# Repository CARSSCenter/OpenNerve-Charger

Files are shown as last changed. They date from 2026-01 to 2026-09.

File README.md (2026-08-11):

## About
This repository holds the PCBA files, firmware, and design files for the OpenNerve charger.
The charger is designed to be compatible with the [OpenNerve Implantable Pulse Generator](https://github.com/CARSSCenter/OpenNerve-Implantable-Pulse-Generator) and to inductively charge it at 300kHz.

charger

## Instructions for Use
BTNs behavior 
Regarding the button functionalities:

    BTN1 changes the state from WAIT to SCAN. If pressed during CHARGE state, it interrupts charging and returns to WAIT.
    BTN2 performs an immediate MCU reset from any state. Use this to recover from a firmware hang without disconnecting power.
    BTN3 enables DFU mode and resets the device to boot in DFU mode.

DFU mode allows firmware updates over USB-C.

LED behavior
The left LED shows the current state:

    OFF → WAIT
    Blue → SCAN
    White → SLOW_CHARGE_AND_SCAN 
    Yellow → CHARGE (connected and charging)

The middle LED turns Green when charging is complete.

Below is a more detailed summary of the firmware state machine, main transitions, and LEDs colors:

States: INITIALIZATION, WAIT, SCAN, SLOW_CHARGE_AND_SCAN, CHARGE

Note: BTN2 (MCU reset) is available in all states and bypasses the state machine entirely. Pressing BTN2 disables WPT and the VCC regulator, then immediately resets the MCU. The device boots back to WAIT.

STATE: INITIALIZATION (initializes BLE, WPT, and PMC subsystems)

    BLE_INITIALIZED → WAIT
    BTN2 PRESSED → MCU RESET
    BUTTON_DFU_PRESSED (BTN3) → DFU mode

STATE: WAIT

    BTN1 PRESSED → SCAN
    BTN2 PRESSED → MCU RESET
    BTN3 PRESSED → DFU mode

STATE: SCAN (Blue Left LED ON)

    BLE_DEVICE_FOUND → CHARGE
    BLE_SCAN_TIMEOUT → SLOW_CHARGE_AND_SCAN
    BTN2 PRESSED → MCU RESET
    BTN3 PRESSED → DFU mode

STATE: SLOW_CHARGE_AND_SCAN (White Left LED ON)

    BLE_DEVICE_FOUND → CHARGE
    BLE_SCAN_TIMEOUT → WAIT
    WPT_SCAN_TIMEOUT → WAIT
    BTN2 PRESSED → MCU RESET
    BTN3 PRESSED → DFU mode

STATE: CHARGE (Yellow Left LED ON / middle LED Green when complete)

    CHARGE_COMPLETE → WAIT (middle LED Green ON)
    BTN1 PRESSED → WAIT (stop charge)
    WPT_SCAN_TIMEOUT → WAIT
    TEMPERATURE_CRITICAL (IPG ≥ 41°C) → WAIT (thermal protection)
    BTN2 PRESSED → MCU RESET
    BUTTON_DFU_PRESSED (BTN3) → DFU mode

In summary, after the charger is connected and initialization finishes, the device enters the WAIT state. If BTN1 is pressed, the device enters SCAN mode and the left LED turns blue. If a device is found, the charger transitions to CHARGE and the left LED turns yellow. If no device is found, the charger enters SLOW_CHARGE_AND_SCAN and the left LED turns white. If the device is still not found after that period, the system returns to WAIT (all LEDs off).
If a device is found during the slow scan, the system transitions to CHARGE. Once charging is completed, the middle LED turns green and the system returns to WAIT. During charging, if BTN1 is pressed, the device returns to the WAIT state. Charging also stops automatically if the IPG temperature rise above 41°C (thermal protection) or if the WPT status times out.
If the firmware becomes unresponsive at any point, BTN2 can be used to reset the MCU and return to WAIT without disconnecting power.

## Instructions for Firmware Development and Flashing
Instructions on how to set up the development environment and compile firmware can be found in the firmware folder's [readme](Firmware/README.md).
### To flash:
1. Install J-Link software: https://www.segger.com/downloads/jlink (when installing, check the box to install legacy USB Driver)
2. Attach J-Link EDU Mini USB cable to Windows computer and in Device Manager confirm that J-Link driver is under USB devices (If it is not there, start J-Link Configurator, right-click on J‐Link EDU Mini, Update FW > Configure > select WinUSB driver > OK)
3. Attach Tag-Connect cable to the charger PCB, open the J-Flash Lite, confirm that Target device is NRF52, and click OK.
4. Click Erase Chip to remove previous FW.
5. Download the two hex files from the Firmware folder.
6. Flash the SoftDevice:
    * Click the “…” button and select 140_nrf52_7.2.0_softdevice.hex 
    * Click Program Device
7. Flash the application:
    * Click the “…” button and select wpt-charger.hex 
    * Click Program Device
      
## Contributors
* [Focus Uy](https://focus.uy/) 
* [Medipace Inc](https://www.medipaceinc.com/) 

## Disclaimer
The contents of this repository are subject to revision. No representation or warranty, express or implied, is provided in relation to the accuracy, correctness, completeness, or reliability of the information, opinions, or conclusions expressed in this repository.

The contents of this repository (the “Materials”) are experimental in nature and should be used with prudence and appropriate caution. Any use is voluntary and at your own risk.

The Materials are made available “as is” by USC (the University of Southern California and its trustees, directors, officers, employees, faculty, students, agents, affiliated organizations and their insurance carriers, if any), its collaborators Med-Ally LLC and Medipace Inc., and any other contributors to this repository (collectively, “Providers”). Providers expressly disclaim all warranties, express or implied, arising in connection with the Materials, or arising out of a course of performance, dealing, or trade usage, including, without limitation, any warranties of title, noninfringement, merchantability, or fitness for a particular purpose.

Any user of the Materials agrees to forever indemnify, defend, and hold harmless Providers from and against, and to waive any and all claims against Providers for any and all claims, suits, demands, liability, loss or damage whatsoever, including attorneys' fees, whether direct or consequential, on account of any loss, injury, death or damage to any person or (including without limitation all agents and employees of Providers and all property owned by, leased to or used by either Providers) or on account of any loss or damages to business or reputations or privacy of any persons, arising in whole or in part in any way from use of the Materials or in any way connected therewith or in any way related thereto.

The Materials, any related materials, and all intellectual property therein, are owned by Providers.

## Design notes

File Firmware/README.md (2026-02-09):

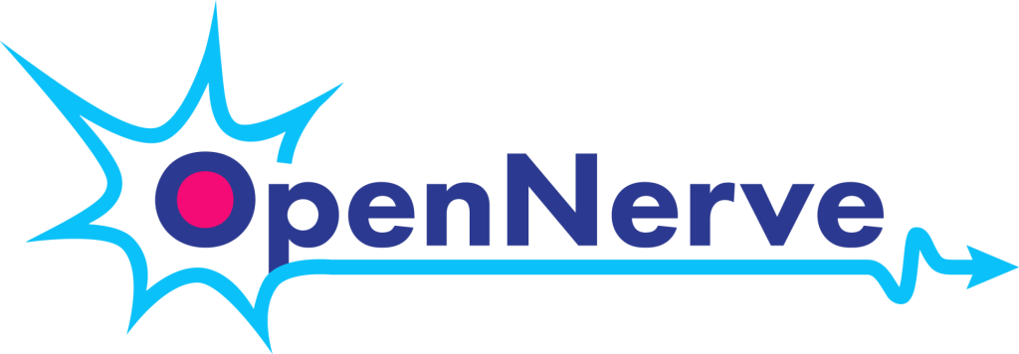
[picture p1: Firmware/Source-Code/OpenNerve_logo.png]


# WPT Charger Embedded Software Development

## Generalities
This repository is dedicated to the development of the WPT Charger embedded software. 

## Getting Started
This section outlines the essential steps to establish a functional environment for building and flashing the application to the WPT Charger. If you are planning to engage in development, refer to the Development section for additional steps that must be followed.

### Install SEGGER IDE
The SEGGER IDE v8.10c is currently being used to compile and flash the application. You can download it [here](https://www.segger.com/downloads/embedded-studio). 

## Development
If you are involved in the development of this project, in addition to the Getting Started section, follow the next steps to set up your development environment.

### Install Python
Install [Python 3.11.3](https://www.python.org/downloads/).

ⓘ Note: If you are running Linux or macOS, consider using `pyenv` to install multiple, independent Python versions.

### Install Git
Install [Git](https://git-scm.com/downloads).

### Set build tool paths
Set build tool paths to use the build tool. Inside the `build_tool` path you will find the `config.ini.example` file. You should copy this, rename it to `config.ini`, and edit it to set your own paths. In addition, you should update the environment variables by adding the `bin` directory of SEGGER to the system's `PATH`. 
After this, you can run the build tool in a Windows PowerShell in build tool path using one of these commands depending on whether you want to build for the devkit or the PCBA:
```
py .\run_build_tool.py --board devkit
```
```
py .\run_build_tool.py --board pcba
```

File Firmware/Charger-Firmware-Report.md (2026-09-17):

# WPT Charger — Firmware Implementation Report

**Hardware:** Hornet WPT Charger PCBA
**MCU:** nRF52840 (via nRF5 SDK)
**Repo path:** `Firmware/Source-Code/`

---

## 1. Overview

The charger firmware manages the complete wireless power transfer (WPT) charging session from user button press to battery full. It communicates with the IPG entirely through BLE advertisement scanning — the IPG broadcasts its charging status, thermistor readings, and GPIO state in a Manufacturer-Specific Data (MSD) payload every second while charging, and the charger uses that data to make power and thermal decisions.

The firmware is built on an **event-driven architecture (EDA)** framework. The application layer, BLE service, WPT service, and PMC service each run their own state machines and communicate exclusively by sending events to each other's ports. No state machine inspects another's internal state directly.

---

## 2. Hardware Overview

### 2.1 WPT Controller — LTC4125

The LTC4125 is the wireless power transmitter IC. In normal operation, LTC4125 autonomously runs an "Optimum Power Search (OPS)" algorithm to find the power level at which the receiver (IPG) is best coupled, using the reflected impedance from the secondary coil to determine best coupling. However, this firmware operates differently; by actively driving the `PTH1`/`PTH2` pins via a 16-bit SPI DAC (DAC80504), the pulse width / power transfer is directly controlled (higher DAC voltage → larger allowed duty cycle → more power delivered).

There are 13 DAC steps (0–12), each corresponding to an increasing power transmission level. It is important to understand what the step actually sets: PTH is a **ceiling** on the LTC4125's internal pulse-width search, not a forced output level. Lowering the step changes delivered power only once the ceiling constrains the search below what the load is drawing. Consequently the control algorithm searches for the lowest ceiling the IPG still accepts — see **6.3 Adaptive Power Control** — and PGOOD typically stays high through several descending steps before anything changes.

| DAC voltage | Step | Role |
|---|---|---|
| 400 mV | 0 (minimum) | Floor of the search range |
| 500 mV | 1 | Cold-start level (`COLD_START_LEVEL`) — the reset level and the first step of the cold-start ramp |
| … | … | Cold-start ramp steps, one every 30 s |
| 1600 mV | 12 (maximum) | Maximum — top of the cold-start ramp |

**CTD pin:** LTC4125 `CTD` (pin 14) has a 36 pF capacitor to GND, which sets the delay between OPS cycles. MCU pin **P0.05 (`WPT_CTD_CTRL`)** drives a MOSFET gate; when that MOSFET is on, it shorts the capacitor and ties `CTD` directly to GND.

`WptManager::ConfigureGpios()` configures P0.05 as an output and writes it **HIGH** during initialization, then never changes it — so for the entire session the MOSFET is on and `CTD` is held at GND, bypassing the 36 pF timing capacitor.

> ⚠️ **Unresolved — needs a datasheet check and a scope on pin 14.** Three things point the same direction and have not been reconciled:
> - The GPIO configuration sits under a comment claiming it is "commented out because the CTD pin is not implemented in the prototype." It is not commented out; it is live code.
> - `Wpt_LTC4125::StopSearch()` and `ResumeSearch()` (`hal_wpt.cpp:59-69`) are empty stubs whose own comments state *"Write 1 to the CTD pin to stop the search"* and *"Write 0 to the CTD pin to resume."* By that convention, initialization writes the **stop-search** value, and the functions intended to control it do nothing. `StopWptScan()` therefore has no effect.
> - An earlier revision of this report asserted that grounding CTD stops the search after the first OPS cycle.
>
> Against that, power delivery demonstrably works and PGOOD does go high in testing. Either the polarity interpretation is wrong, or a single OPS cycle is sufficient given that the DAC drives PTH directly and overrides the search anyway. Worth settling before relying on `StopSearch()`/`ResumeSearch()` for anything.

### 2.2 DAC — DAC80504

16-bit quad-channel SPI DAC. Only CHANNEL_1 is used to drive `PTH1`/`PTH2`. `Dac80504::Init()` configures it with `ReferenceDivider::DIVIDER_OFF` and **`Gain::DOUBLE_GAIN`** (`hal_dac.cpp:35`), so with `REFERENCE_VOLTAGE = 2500 mV` the full-scale output is **5000 mV**, not 2500 mV. The `LDAC` pin is toggled after each SPI write to latch the new value.

```
DAC voltage = 400 mV + (step × 100 mV)    step ∈ [0, 12]
```

> **Note:** `hal_dac.h:65` defines `MAX_OUTPUT_VOLTAGE = 2500`, which is inconsistent with the configured 2× gain. That constant is unused anywhere in the codebase — do not treat it as the full-scale value.

### 2.3 Key GPIO / Analog Pins

Values below are for `BOARD == PCBA`. `hal_pinout.h:65-111` defines a materially different `DEV_KIT` pinout (e.g. `WPT_EN` on P0.28, `WPT_NTC` on P0.29 as a plain GPIO rather than AIN6) — check the build's `BOARD` setting before using these for bring-up.

| Signal | Pin | Direction | Notes |
|---|-----|---|---|
| `WPT_EN` | P1.15 | Output | LOW = LTC4125 enabled (active-low) |
| `WPT_STAT` | P0.7 | Input | LTC4125 load-detection status (see §11 — `GetStat()` is a stub) |
| `WPT_CTD_CTRL` | P0.5 | Output | HIGH = MOSFET on = LTC4125 `CTD` shorted to GND (see §2.1) |
| `WPT_NTC` | AIN6 | Analog | Local NTC thermistor on charger PCB (see §11 — conversion is broken) |
| `WPT_IMON` | AIN5 | Analog | Coil current monitor |
| `DAC_CS` | P0.11 | Output | DAC chip select (SPI) |
| `DAC_LDAC` | P0.12 | Output | DAC latch |
| `PMC_VCC_EN` | P0.20 | Output | Enables power management circuit |
| `SCLK` | P1.9 | Output | SPI clock |
| `MOSI` | P1.8 | Output | SPI MOSI |
| `MISO` | P0.8 | Input | SPI MISO |

### 2.4 LED Indicators

| LED state | Meaning |
|---|---|
| Blue (scanning) | Scanning for IPG — BLE scan active |
| White (slow charge) | Coil powering up a switched-off IPG — waiting for BLE |
| Yellow (charging) | IPG found, WPT active, batteries charging |
| Green (charged) | All batteries full |
| Magenta (manual) | **Debug builds only** — `StateManual`, operator driving the coil over RTT (§4.7) |

---

## 3. Firmware Architecture

### 3.1 Layer Structure

```
┌─────────────────────────────────────────────┐
│              Application Layer              │
│  app_state_machine.cpp / app_system.cpp     │
│  state_wait / state_scan / state_charge /   │
│  state_slow_charge_and_scan /               │
│  state_initialization /                     │
│  state_manual (debug builds only)           │
├─────────────────────────────────────────────┤
│              Service Layer                  │
│  BLE: svc_ble_manager / svc_ble_subsystem   │
│  WPT: svc_wpt_manager / svc_wpt_subsystem   │
│  PMC: svc_pmc_subsystem                     │
│  Debug: svc_debug_console (debug builds)    │
├─────────────────────────────────────────────┤
│               Core Layer                    │
│  EDA framework: state machines, active      │
│  objects, ports, timers, queues             │
├─────────────────────────────────────────────┤
│               HAL Layer                     │
│  hal_ble / hal_wpt / hal_dac / hal_led /    │
│  hal_dfu / hal_adc                          │
└─────────────────────────────────────────────┘
```

### 3.2 Port / Event Model

Each subsystem exposes a **port** (a message queue). State machines communicate by calling `Port::SendEvent(event, optData)` rather than calling each other directly. This decouples layers — the application layer sends `WptPort::WPT_POWER_ON` and the WPT service handles it in its own context.

**System events** (`app_port.h`):

| Event | Meaning |
|---|---|
| `BLE_INITIALIZED` | BLE stack ready |
| `BLE_DEVICE_FOUND` | IPG advertisement received |
| `BLE_SCAN_TIMEOUT` | No advertisement within scan window |
| `WPT_SCAN_TIMEOUT` | WPT-level scan timed out |
| `BATTERY_CHARGED` | All batteries full |
| `BUTTON_PRESSED` | User pressed the power button |
| `BUTTON_DFU_PRESSED` | DFU mode button combo |
| `TURN_OFF` | Formerly the thermal shutdown path; thermal faults no longer reach the application layer at all (§6.5). In a **production** build nothing sends it and the handler at `state_charge.cpp:60` is unreachable. In a **debug** build the RTT console's `n` command sends it to leave `StateManual` (`state_manual.cpp:67`). |
| `MANUAL_TAKEOVER` | **Debug builds only** (0x12). Sent by the RTT console's `m` command; each operational state transitions to `StateManual` on it (§4.7). Safe despite `MAX_EVENT_ENUM_LENGTH = 20`: `SystemPort::ExecuteEvent` dispatches straight to the state machine and never indexes `mEventCallback`. |

**WPT service events** (`svc_wpt_port.h`):

| Event | Value | Meaning |
|---|---|---|
| `WPT_POWER_ON` | 0x03 | Enable LTC4125, begin OPS |
| `WPT_POWER_OFF` | 0x07 | Disable LTC4125 |
| `WPT_FAULT_CONDITION` | 0x08 | Fault detected |
| `WPT_BATTERY_CHARGING` | 0x09 | BLE confirms charging in progress |
| `WPT_BATTERY_CHARGED` | 0x0B | BLE confirms all batteries full |
| `WPT_SLOW_CHARGE` | 0x0C | Begin the open-loop cold-start ramp (step 1, +1 step every 30 s until an advertisement or step 12) |
| `WPT_SCAN_TIMEOUT` | 0x0D | Power search timed out |
| `WPT_ADJUST_POWER` | 0x0E | Set specific DAC step. Handled in `StateCharging` and `StateSlowCharge`; **dropped** in `StateIdle` (§6.1) |
| `WPT_FAULT_PAUSE` | 0x0F | Suspend coil output; `optDataAddress` carries the `PauseReason_e` (`PAUSE_THERMAL`, `PAUSE_OVP`, or in debug builds `PAUSE_MANUAL`) |
| `WPT_FAULT_RESUME` | 0x10 | Clear one pause reason; `optDataAddress` carries the `PauseReason_e` |
| `WPT_MANUAL_IDLE` | 0x11 | **Debug builds only.** Sent by `StateManual::Entry()`; every WPT state stops the coil and settles in `StateIdle` with fault monitoring only (§4.7) |

`WPT_FAULT_PAUSE`/`WPT_FAULT_RESUME` replaced the earlier `WPT_THERMAL_PAUSE`/`WPT_THERMAL_RESUME` pair at the same event values, generalized to carry a reason so thermal and OVP can share one pause mechanism (see §6.2). The debug console reuses the same pair with `PAUSE_MANUAL` for its coil stop/start. Manual mode adds exactly one WPT event, `WPT_MANUAL_IDLE` (0x11, debug builds only) — kept to one because callbacks registered on a port are stored in a 20-entry array indexed by event ID (`eda_port.h:13`).

---

## 4. Application State Machine

### 4.1 States and Transitions

```
                     power on
                         │
                         ▼
                ┌─────────────────┐
                │  StateInit      │ ← BLE + WPT + PMC subsystems initialized
                └────────┬────────┘
                         │ BLE_INITIALIZED
                         ▼
         ┌──────────────────────────────┐
         │           StateWait          │ ← LEDs off, idle
         └──────────────┬───────────────┘
                        │ BUTTON_PRESSED
                        ▼
         ┌──────────────────────────────┐
         │          StateScan           │ ← Blue LED, BLE scanning (10 s)
         └────┬─────────────────────────┘
              │                         │
    BLE_DEVICE_FOUND            BLE_SCAN_TIMEOUT
              │                         │
              ▼                         ▼
   ┌──────────────────┐    ┌────────────────────────────┐
   │   StateCharge    │    │   StateSlowChargeAndScan   │ ← White LED
   │  (Yellow LED)    │    │   Cold start: step 1, +1   │
   └──────┬───────────┘    │   every 30 s up to 12      │
          │                │   BLE scanning (390 s)     │
          │                └──────────┬─────────────────┘
          │                          │ BLE_DEVICE_FOUND
          │                          │
          │    ◄─────────────────────┘
          │
          │ BATTERY_CHARGED → StateWait (green LED)
          │ BUTTON_PRESSED  → StateWait
          │ TURN_OFF        → StateWait   (unreachable in production builds — see §3.2)
          │ WPT_SCAN_TIMEOUT → StateWait  (thermal blind-retry give-up only — see §6.5, §11)
```

**Debug builds add `StateManual` (§4.7).** `StateWait`, `StateScan`, `StateSlowChargeAndScan` and `StateCharge` each move to it on `MANUAL_TAKEOVER`; only `TURN_OFF` (the console's `n`) returns it to `StateWait` — Button 1 is ignored there. It is not drawn above because it does not exist in a production build.

### 4.2 StateInitialization

Entry sends `INITIALIZE` to the BLE, WPT, and PMC subsystem ports. When `BLE_INITIALIZED` is received, transitions to `StateWait`. This is the only state where subsystem initialization occurs.

### 4.3 StateWait

Idle state. No LEDs, no scanning, no WPT. Transitions to `StateScan` on `BUTTON_PRESSED`, and in debug builds to `StateManual` on `MANUAL_TAKEOVER`. "No WPT" does not imply VCC_EN is low: arriving from `StateCharge` leaves the rail up, because `StateCharge::Exit()` never sends `PMC_POWER_OFF` (§4.6).

### 4.4 StateScan

```
Entry:
  BlePort::START_SCANNING
  hal::Leds::LedScanOn(true)       ← blue LED

DispatchEvent:
  BLE_DEVICE_FOUND:
    mWptManager.StartIpgTemperaturePgoodMonitoringTimer()
    → ChangeState(StateCharge)

  BLE_SCAN_TIMEOUT:
    mWptManager.StopIpgTemperaturePgoodMonitoringTimer()
    → ChangeState(StateSlowChargeAndScan)

  BUTTON_DFU_PRESSED:
    hal::Dfu::start_dfu_mode()

  MANUAL_TAKEOVER:                    (debug builds only)
    → ChangeState(StateManual)

Exit:
  WptPort::WPT_POWER_ON            ← transitions WPT SM StateIdle → StateCharging
  hal::Leds::LedScanOn(false)
```

When no IPG is found within the 10-second scan window, the charger assumes the IPG may be powered off. It enters `StateSlowChargeAndScan`, which ramps the coil up from step 1 to boot a drained IPG from wireless power, and scans for up to 390 seconds to catch the BLE advertisement after initialization.

Note the ordering: `ChangeState` runs `StateScan::Exit()` (which sends `WPT_POWER_ON`, taking the WPT SM from `StateIdle` to `StateCharging`) *before* `StateSlowChargeAndScan::Entry()` sends `WPT_SLOW_CHARGE`. So `WPT_SLOW_CHARGE` is always handled by `StateCharging`, never by the WPT SM's own `StateSlowCharge` — see §11.

### 4.5 StateSlowChargeAndScan

```
Entry:
  BleManager::SetScanTimeout(390000)    ← 390 s: full cold-start ramp + 30 s at max
  BlePort::START_SCANNING
  WptPort::WPT_SLOW_CHARGE              ← cold start: ramp from step 1, +1 every 30 s
  PmcPort::PMC_POWER_ON                 ← VCC_EN high (5V rail for LTC4125)
  hal::Leds::LedChargingSlow(true)      ← white LED

DispatchEvent:
  BLE_DEVICE_FOUND:
    mWptManager.StartIpgTemperaturePgoodMonitoringTimer()
    → ChangeState(StateCharge)          ← WPT and VCC stay enabled

  BLE_SCAN_TIMEOUT:
    BlePort::STOP_SCANNING
    mWptManager.StopIpgTemperaturePgoodMonitoringTimer()
    WptPort::WPT_POWER_OFF
    PmcPort::PMC_POWER_OFF              ← VCC_EN low
    → ChangeState(StateWait)

  WPT_SCAN_TIMEOUT:
    WptPort::WPT_POWER_OFF
    PmcPort::PMC_POWER_OFF              ← VCC_EN low
    → ChangeState(StateWait)

  BUTTON_DFU_PRESSED:
    hal::Dfu::start_dfu_mode()

  MANUAL_TAKEOVER:                    (debug builds only)
    → ChangeState(StateManual)

Exit:
  BleManager::SetScanTimeout(10000)     ← restore default SCAN_TIMEOUT_MS
  hal::Leds::LedChargingSlow(false)
```

**Cold-start power profile (ramp, since 2026-09-17):** with no BLE there is no PGOOD or OVP telemetry, so this window is open-loop by necessity. `WptManager::StartColdStartRamp()` sets `COLD_START_LEVEL` (step 1, 500 mV) and starts the periodic `mColdStartRampTimer`. Every `COLD_START_STEP_MS` (30 s) `ColdStartRampStep()` raises the level by one step, until:

| Condition | Action |
|---|---|
| An advertisement has arrived since the ramp started | Stop the timer, log `Cold start ramp ended at level N`; the closed loop keeps that level (§6.3) |
| A fault pause is active | Skip the step (defensive; faults need telemetry, so this should not occur) |
| Level already at the maximum (12) | Stop the timer, log `holding at maximum level`, stay there for the rest of the window |
| Otherwise | `SetPowerLevel(m_level + 1)`, log `Cold start ramp stepping up to level N` |

`StartIpgTemperaturePgoodMonitoringTimer()` also stops the ramp, so it ends as soon as the app sees the IPG; `DisableWpt()` stops it when the window times out. The ramp's own advertisement check compares against the count recorded when the ramp started — the counter runs from boot, so "no advertisement yet" means *unchanged*, not zero.

**Why a ramp.** Jumping straight to step 7 (the previous cold-start level) occasionally damaged the IPG's rectifier. The ramp brings power up one 100 mV step at a time, and nothing anywhere now raises the level by more than one step at once.

**Window length.** `SCAN_TIMEOUT_SLOW_CHARGE_MS` = 390 s = 12 steps × 30 s (step 1 → 12) plus 30 s at step 12. It must be kept in sync with `COLD_START_LEVEL` and `COLD_START_STEP_MS` by hand. The previous optional jump to maximum (`COLD_START_ESCALATION_ENABLED`, `COLD_START_ESCALATE_MS`, §8.7) has been removed.

**Key design decisions on BLE_DEVICE_FOUND:** When the IPG is detected, WPT and VCC are left enabled intentionally. `StateCharge::Entry()` sends `WPT_POWER_ON` to ensure the WPT service is in `StateCharging` regardless of which path led here, and `PMC_POWER_ON` is a no-op in `PmcStateEnable` (PMC was already enabled in this state's `Entry()`). This avoids any disable/enable round-trip that would briefly cut power to the still-booting IPG.

**Why PMC_POWER_ON is needed in this state:** `PIN_PMC_VCC_EN` (P0.20) controls the 5V supply rail that powers the LTC4125. Without it, the LTC4125 has no supply and cannot transmit power even if `WPT_EN` is asserted. Since `StateSlowChargeAndScan` is specifically for charging a fully-discharged IPG (no BLE yet), VCC must be enabled here, not deferred to `StateCharge`.

### 4.6 StateCharge

```
Entry:
  PmcPort::PMC_POWER_ON
  hal::Leds::LedCharging(true)          ← yellow LED
  WptPort::WPT_POWER_ON                 ← ensures WPT active from any entry path
  mWptManager.StartIpgTemperaturePgoodMonitoringTimer()

DispatchEvent:
  BATTERY_CHARGED:
    hal::Leds::LedCharged(true)         ← green LED
    → ChangeState(StateWait)

  BUTTON_PRESSED:
    → ChangeState(StateWait)

  TURN_OFF:
    → ChangeState(StateWait)            ← unreachable in production builds (§3.2)

  BLE_SCAN_TIMEOUT:
    BlePort::START_SCANNING             ← restart scan, do NOT exit charge state

  WPT_SCAN_TIMEOUT:
    → ChangeState(StateWait)            ← only sender today: thermal blind-retry give-up (§6.5);
                                          the GetStat() path is a stub (§11)

  BUTTON_DFU_PRESSED:
    hal::Dfu::start_dfu_mode()

  MANUAL_TAKEOVER:                    (debug builds only)
    → ChangeState(StateManual)

Exit:
  BlePort::STOP_SCANNING
  WptPort::WPT_POWER_OFF
  hal::Leds::LedCharging(false)
```

**BLE_SCAN_TIMEOUT handling in StateCharge:** Once the IPG detects wireless power, it typically reduces its BLE advertising rate to conserve power. The 10-second scan timeout would otherwise kick the charger out of `StateCharge` and disable WPT. Instead, when a scan timeout fires while in `StateCharge`, BLE scanning is restarted immediately. The charger remains in `StateCharge` and the monitoring loops continue uninterrupted. WPT is never disabled on a scan timeout in this state.

That reduced advertising rate has a second consequence the control loop has to handle directly: `GetAdvertisementData()` returns the last parsed advertisement indefinitely, so a PGOOD sample can be seconds old and predate the power step being evaluated. See §5.2 and §6.3 for the freshness guard that addresses it.

**Thermal and OVP faults do not exit this state.** Both are handled entirely inside the WPT service layer by pausing coil output while leaving the state machines in place (§6.2). The application layer stays in `StateCharge`, the yellow LED stays on, and recovery needs no button press.

**`Exit()` does not drop VCC_EN.** No `PMC_POWER_OFF` is sent, so leaving `StateCharge` on `BATTERY_CHARGED` or `BUTTON_PRESSED` parks PMC in `PmcStateEnable`: the LTC4125 stays powered, though disabled (`WPT_EN` high), in `StateWait`. Harmless for coil output, but worth knowing when probing VCC_EN — and the reason `StateManual::Exit()` sends `PMC_POWER_OFF` explicitly (§4.7).

### 4.7 StateManual (debug builds only)

Exists only when `WPT_MANUAL_DEBUG_MODE` is 1 (§10); a production build contains none of it. It lets an operator drive the coil by hand over RTT while normal logging continues. Background and rationale are in §8.4.

```
Entry:
  DebugConsole::OnManualEntered()         ← the state owns the console's manual flag
  PmcPort::PMC_POWER_ON                   ← VCC_EN high
  BlePort::START_SCANNING                 ← IPG telemetry for the warn-only monitors
  WptPort::WPT_MANUAL_IDLE                ← queued behind the previous state's WPT events:
                                            coil off, timers stopped, ramp cancelled,
                                            level → step 1, WPT SM → StateIdle, then
                                            fault monitoring only
  magenta LED

DispatchEvent:
  TURN_OFF:            → ChangeState(StateWait)   ← console 'n' — the only way out
  BUTTON_PRESSED:      ignored, logged            ← Button 1 disabled in manual mode
  BLE_SCAN_TIMEOUT:    BlePort::START_SCANNING    ← re-arm, no state change
  BATTERY_CHARGED:     BlePort::START_SCANNING    ← re-arm; redundant since 2026-09-17 (§8.8), harmless
  BUTTON_DFU_PRESSED:  hal::Dfu::start_dfu_mode()
  (WPT_SCAN_TIMEOUT and BLE_DEVICE_FOUND deliberately absent)

Exit:
  DebugConsole::OnManualExited()
  mWptManager.StopIpgTemperaturePgoodMonitoringTimer()
  WptPort::WPT_POWER_OFF
  BlePort::STOP_SCANNING
  PmcPort::PMC_POWER_OFF                  ← required; nothing else drops the rail
  LEDs off
```

It is entered from `StateWait`, `StateScan`, `StateSlowChargeAndScan` or `StateCharge` on `MANUAL_TAKEOVER`, which the console sends on `m`. Behaviour that must not happen in manual mode is expressed as a missing case rather than a runtime check, which is why a scan timeout with no IPG present cannot end the session the way it does in `StateSlowChargeAndScan` (§8.4). Whatever the previous state was doing — scanning, a cold start, an automatic charge — is stopped on entry, and the board idles with the coil off until `s`. Button 2, which resets the MCU from its ISR, remains the physical escape hatch.

Console commands (`svc_debug_console.cpp`, polled every 100 ms on the SEGGER RTT down-channel):

| Key | Action |
|---|---|
| `m` / `n` | enter / leave manual mode |
| `s` | coil start: `PMC_POWER_ON`, `WPT_POWER_ON`, `WPT_FAULT_RESUME(PAUSE_MANUAL)`, `WPT_ADJUST_POWER` — in that order, because WPT `StateIdle` drops the last two (§6.1) |
| `x` | coil stop: `WPT_FAULT_PAUSE(PAUSE_MANUAL)`. VCC_EN stays up, so only `WPT_ENn` moves |
| `+` / `-`, `0`–`9`, `a`–`c` | step, or set, PTH 0–12 via `SetPowerLevelManual()` |
| `?` / `h` | status (mode, coil, pause mask, app state, level and mV, bounds, IPG bits, dead-man) / help |

Thermal and OVP are warn-only (§6.5, §6.6), the raw IPG fault bits are logged every fault tick, and a dead-man timeout pauses the coil after 10 minutes with no keystroke.

**Why entry goes through a WPT event (fixed 2026-09-10).** An earlier revision did the WPT setup directly in `Entry()` and failed for three of the four entry states, all for one reason. `ChangeState()` runs the previous state's `Exit()` and `StateManual::Entry()` back-to-back on the SYSTEM task, which runs at priority `app` (4) against the WPT task's `svc_1` (1), so whatever the previous `Exit()` queued to the WPT port is processed *after* `Entry()`:

| Entered from | Queued by the previous `Exit()` | Effect of direct setup in `Entry()` |
|---|---|---|
| `StateWait` | nothing | worked |
| `StateScan` | `WPT_POWER_ON` | coil came on once VCC_EN rose |
| `StateSlowChargeAndScan` | nothing — coil already on | coil stayed on; the running cold-start ramp kept raising the level |
| `StateCharge` | `WPT_POWER_OFF` | its `DisableWpt()` stopped the fault timer `Entry()` had just started |

`WPT_MANUAL_IDLE` is queued behind those events on the same port, so FIFO order makes it the last word; its handler is `WptManager::EnterManualIdle()`. A cold-start ramp step expiring at the same moment cannot leave the level raised: `DisableWpt()` posts the timer's stop before `ResetPowerControl()`, and the FreeRTOS timer task (priority 2) preempts the WPT task (1) on that post, so the step runs before the reset, not after. Manual idle therefore rests at step 1, and `s` starts the coil there. The one visible residue is entry from `StateScan`, whose queued `WPT_POWER_ON` still drives `WPT_ENn` low for well under a millisecond before `WPT_MANUAL_IDLE` is processed — normally with VCC_EN still off, since `StateScan` never raises it.

The same revision let Button 1 leave manual mode without clearing the console's flag, which demoted thermal and OVP to warn-only in the next automatic session. Button 1 is now ignored in `StateManual`, and the flag is owned by the state itself (`OnManualEntered()`/`OnManualExited()`), so the two cannot disagree.

---

## 5. BLE Service Layer

### 5.1 BLE State Machine

Two states:

- **StateIdle** — On `INITIALIZE`: calls `BleManager::Init()`, sends `BLE_INITIALIZED`. On `START_SCANNING` → `StateScanning`.
- **StateScanning** — Entry: `BleManager::StartScanning()`. On `STOP_SCANNING` or `SCAN_TIMEOUT` → `StateIdle`. Exit: `BleManager::StopScanning()`.

### 5.2 BLE Manager

`BleManager` owns scanning and advertisement parsing. Its scan timeout is a software watchdog timer (`eda::Timer`) that fires if no valid advertisement arrives within `mScanTimeoutMs`. On each valid IPG advertisement received, the timer is restarted (from ISR context) — so the timeout only fires if the IPG goes silent.

**Scan timeout values:**

| Constant | Value | Used in |
|---|---|---|
| `SCAN_TIMEOUT_MS` | 10,000 ms | `StateScan`, `StateCharge` |
| `SCAN_TIMEOUT_SLOW_CHARGE_MS` | 390,000 ms | `StateSlowChargeAndScan` — sized for the cold-start ramp (§4.5) |

`SetScanTimeout(ms)` must be called before `StartScanning()` (or between advertisements) to take effect. `StateSlowChargeAndScan::Entry()` calls it with `SCAN_TIMEOUT_SLOW_CHARGE_MS`; `StateSlowChargeAndScan::Exit()` restores `SCAN_TIMEOUT_MS`. The cold-start window is currently the longer of the two (390 s vs 10 s).

`eda::Timer::Start(period)` / `StartFromISR(period)`, which these timeouts use, converted nothing before 2026-09-17 and passed milliseconds to FreeRTOS as ticks. At `configTICK_RATE_HZ` = 1024 every scan window ran about 2.3 % short (10 s → 9.77 s; 390 s would have been 381 s). They now apply `pdMS_TO_TICKS()`, as the constructor always did.

**Advertisement counter.** `BleManager` maintains `mAdvertisementCounter`, incremented in `ParseManufacturerSpecificData()` immediately after the payload fields are written and before `DEVICE_FOUND` is sent, exposed via `GetAdvertisementCount()`. Ordering matters: any consumer that observes a new count is guaranteed to see the data that arrived with it.

It exists because `GetAdvertisementData()` alone gives no way to tell how old its contents are, and two separate failure modes follow from that:

- **Validity.** A count of zero means no advertisement has *ever* been parsed, so `mAdvertisementData` is still all zeros. Since the IPG's fault bits are active-low, all-zero reads as *every fault asserted*, and the all-zero thermistor fields make the resistance calculation degenerate into a 50 °C reading. Both the OVP and temperature monitors bail out while the count is zero — without that, the charger would fault-pause on every startup. The counter is never reset, so after the first session "no advertisement in *this* session" has to be tested against a value recorded at session start (`ResetPowerControl()` and `StartColdStartRamp()` do this), not against zero.
- **Freshness.** An unchanged count between two control decisions means no new telemetry arrived, so the previous decision has not been observed yet. The power control loop skips such cycles rather than acting on a stale PGOOD (§6.3).

### 5.3 Advertisement Parsing

The charger scans for manufacturer-specific data with company ID `0xF0F0` (production IPG firmware). When a matching advertisement is found, `ParseManufacturerSpecificData()` extracts the payload and stores it in `mAdvertisementData`. The timer is then restarted and `BlePort::DEVICE_FOUND` is sent to the application layer.

**IPG MSD layout** (bytes relative to start of MSD field, after length and type bytes):

```
index+2, index+3  Company ID (little-endian): 0xF0F0
index+4           msd[0]  DVDD voltage        × 100 mV
index+5           msd[1]  Battery A voltage   × 100 mV
index+6           msd[2]  Battery B voltage   × 100 mV
index+7           msd[3]  Impedance A         × 10 mV
index+8           msd[4]  Impedance B         × 10 mV
index+9           msd[5]  ThermRef voltage    × 10 mV
index+10          msd[6]  ThermOut voltage    × 10 mV
index+11          msd[7]  ThermOfst voltage   × 10 mV
index+12          msd[8]  GPIO bits 0–7
index+13          msd[9]  GPIO bits 8–13
…
index+27          msd[23] Hardware version
```

**GPIO byte (msd[8]) bit assignments:**

| Bit | Signal | Active level | Meaning when set (1) |
|-----|---|---|---|
| 0 | `VRECT_DETn` | Active-low | No coil detected |
| 1 | `VRECT_OVPn` | Active-low | Rectifier voltage OK |
| 2 | `VCHG_PGOOD` | Active-high | Boost converter output good |
| 3 | `CHG1_STATUS` | — | Battery A idle / charge complete |
| 4 | `CHG1_OVP_ERRn` | Active-low | Battery A OVP OK |
| 5 | `CHG2_STATUS` | — | Battery B idle / charge complete |
| 6 | `CHG2_OVP_ERRn` | Active-low | Battery B OVP OK |
| 7 | `ENG2_SDNn` | Active-low | ENG2 enabled |

> ⚠️ **The parser stores these as raw bits, not normalized booleans.** `GET_VRECT_OVP`, `GET_CHG1_OVP_ERR`, and `GET_CHG2_OVP_ERR` hold the bit exactly as received (`svc_ble_manager.cpp:182,185,187`), so for all three an **asserted fault is 0, not 1**. A natural-looking `if (params.GET_VRECT_OVP)` is inverted and will trip on every healthy advertisement. Only `GET_VCHG_RAIL_SUPPLY_CIRCUIT_POWER_GOOD` (bit 2) is active-high and reads the way its name suggests. Verified end-to-end on 2026-09-10: the IPG packs each pin's level unmodified (`setBitFromGpioState`, `app_mode_ble_active.c:26-47`), the pins are inputs with internal pull-ups (`gpio.c:150-154`, `273-277`), and the two `== 0` compares in `IpgOvpMonitoring()` are the only inversion between the IPG pin and the charger's decision.

**Thermistor bytes** are in units of 10 mV; the parser multiplies by 10 to produce mV for `CalculateTemperatureFromBle()`. Note the IPG clamps each to 0xFF before transmitting (`app_mode_ble_active.c:137-139`), giving a ceiling of 2550 mV, and the 10 mV quantization is ±~0.6 °C at the charger — appreciable against the 2 °C thermal hysteresis band.

**Battery voltage** is packed as:
```
BATTERY_VOLTAGE_MEASURED = (BattA_mV) | (BattB_mV << 16)
where BattA_mV = msd[1] * 100,  BattB_mV = msd[2] * 100
```

`ProcessNewBleData()` splits it back into the two channels for logging (`Battery voltage measured: BattA=… mV BattB=… mV`) and for charge-completion detection (§7). On the current IPG, BattA is unpopulated and reads 0–200 mV; the combined value printed as one integer before 2026-09-17 (e.g. `163840000 mV` = BattB 2500 mV) was unreadable.

---

## 6. WPT Service Layer

### 6.1 WPT State Machine

Four states:

```
StateIdle
  │ WPT_POWER_ON → StateCharging
  │ WPT_SLOW_CHARGE → StateSlowCharge
  │ INITIALIZE: mWptManager.Init()
  │ WPT_MANUAL_IDLE: mWptManager.EnterManualIdle()          (debug builds)
  │ everything else is silently dropped — including WPT_ADJUST_POWER,
  │ WPT_FAULT_PAUSE and WPT_FAULT_RESUME

StateSlowCharge
  │ Entry: mWptManager.EnableWpt()
  │ WPT_POWER_ON / WPT_LOAD_DETECTED → StateCharging
  │ WPT_POWER_OFF → StateIdle (calls mWptManager.DisableWpt())
  │ WPT_SCAN_TIMEOUT → StateIdle
  │ WPT_ADJUST_POWER: mWptManager.AdjustWptPowerTransfer(step)   ← added 2026-09-09
  │ WPT_FAULT_PAUSE:  mWptManager.PauseWpt(reason)   — no state change
  │ WPT_FAULT_RESUME: mWptManager.ResumeWpt(reason)  — no state change
  │ WPT_MANUAL_IDLE: EnterManualIdle() → StateIdle          (debug builds)

StateCharging
  │ Entry: mWptManager.EnableWpt()
  │ WPT_POWER_ON: no-op (already active)
  │ WPT_POWER_OFF → StateIdle (calls mWptManager.DisableWpt())
  │ WPT_SLOW_CHARGE: mWptManager.StartColdStartRamp()
  │ WPT_ADJUST_POWER: mWptManager.AdjustWptPowerTransfer(step)
  │ WPT_BATTERY_CHARGED: no-op (handled by app layer — see §6.4)
  │ WPT_SCAN_TIMEOUT: → WPT_POWER_OFF
  │ WPT_FAULT_CONDITION: → WPT_POWER_OFF
  │ WPT_FAULT_PAUSE:  mWptManager.PauseWpt(reason)   — no state change
  │ WPT_FAULT_RESUME: mWptManager.ResumeWpt(reason)  — no state change
  │ WPT_MANUAL_IDLE: EnterManualIdle() → StateIdle          (debug builds)

StateTest (stub — Entry and DispatchEvent log only, no behavior)
```

**Why the fault cases change no state:** a thermal or OVP pause must stop coil output without tearing down monitoring, because the recovery condition can only be observed by continuing to sample. Staying in `StateCharging` also keeps the application layer in `StateCharge`, so recovery is automatic rather than requiring a button press. Both WPT states carry the cases because the monitoring timers also run while scanning and slow-charging, so a fault can arrive in `StateSlowCharge` and not only in `StateCharging`.

**`StateIdle` drops more than it appears to.** Its `default:` case (`svc_wpt_state_idle.cpp:72`) silently discards every event except `INITIALIZE`, `WPT_POWER_ON`, `WPT_SLOW_CHARGE` and, in debug builds, `WPT_MANUAL_IDLE`. A power adjustment, pause or resume that arrives while the WPT SM is idle is lost, not deferred. Any sequence that must land in `StateCharging` therefore has to send `WPT_POWER_ON` first — which is why the ordering of the debug console's coil-start command is load-bearing (§4.7).

**`StateSlowCharge` used to drop `WPT_ADJUST_POWER` as well.** Every power step arriving there was discarded and the DAC kept its previous value. The state is currently unreachable (§11), so this never bit in practice, but it would have the moment it became reachable. Fixed on 2026-09-09, independently of the debug work.

### 6.2 WPT Manager

`WptManager` is the singleton that owns the LTC4125 and DAC directly.

**`EnableWpt()`:**
1. Writes `m_level` to the DAC, then sets `WPT_EN` LOW (active-low: enables LTC4125) — **only if the pause mask is clear**
2. Starts the 5-second status timeout timer
3. Starts the status monitoring timer (500 ms periodic)

The mask check in step 1 matters because `Entry()` re-runs on the `StateSlowCharge → StateCharging` transition. Without it, a `WPT_POWER_ON` arriving during an active thermal or OVP pause would turn the coil back on underneath that pause. A fault outranks a state entry.

Writing the level first matters because `DisableWpt()` never touches the DAC: without it, a new session's coil came on at whatever level the previous session ended on until the first `WPT_ADJUST_POWER` was handled. On the `StateSlowCharge → StateCharging` re-entry the write repeats the current level and changes nothing.

**`DisableWpt()`:**
1. Sets `WPT_EN` HIGH (active-low: disables LTC4125)
2. Stops the status monitoring timer
3. Stops both monitoring timers (fault and power control)
4. Stops the cold-start ramp timer
5. Calls `ResetPowerControl()` — clears the pause mask, both pause tick counters, the level (back to step 1), the floor/ceiling bounds, and the loop-initialized flag, and records the current advertisement count as the session's baseline

Step 5 is what makes a charge session start clean. An earlier revision left the thermal flag as a static that survived across sessions, so a session that ended while paused would leave it set and the next session's first cool reading would fire a spurious resume.

**`PauseWpt(reason)` / `ResumeWpt(reason)`:**
Thermal and OVP faults share one pause mechanism, arbitrated by a bitmask:

```cpp
enum PauseReason_e : uint8_t {
    PAUSE_THERMAL = 1 << 0,
    PAUSE_OVP     = 1 << 1,
    PAUSE_MANUAL  = 1 << 2,   // debug console only — see §4.7
};
static uint8_t m_pause_reasons;   // coil enabled iff == 0
```

`PauseWpt()` disables the coil only on the first reason set; `ResumeWpt()` re-enables it only once the mask returns to zero. With two independent booleans instead, overlapping faults would resume each other — whichever cleared first would restore power while the other was still asserted. Neither function touches the monitoring timers.

`PAUSE_MANUAL` is set and cleared only by the RTT debug console. Putting it in the same mask means a manual stop cannot be undone by an automatic fault resume, and the "coil enabled iff mask == 0" rule keeps holding without a special case.

**Coil state tracking — `m_coil_enabled` / `IsCoilEnabled()`.** The mask alone cannot say whether the coil is being driven: in WPT `StateIdle` the mask is zero *and* the coil is off. `m_coil_enabled` records the actual drive state. It is set wherever `WptHalInstance.Enable()` really runs — `EnableWpt()` on its unmasked branch, and `ResumeWpt()` when the mask reaches zero — and cleared in `DisableWpt()` and on the first `PauseWpt()`.

**Monitoring timer entry points.** `StartIpgTemperaturePgoodMonitoringTimer()` stops the cold-start ramp and starts both the fault timer and the power-control timer (§6.3). `StartFaultMonitoringOnly()` starts only the fault timer; manual mode uses it so thresholds are still evaluated while the titration loop never runs. In debug builds `EnterManualIdle()` combines what manual mode needs on entry — `DisableWpt()` then `StartFaultMonitoringOnly()` — and runs on the WPT task via `WPT_MANUAL_IDLE` (§4.7). There is a single stop, `StopIpgTemperaturePgoodMonitoringTimer()`, which stops both.

**Accessors for the debug console.** `SetPowerLevelManual()` routes through `SetPowerLevel()`, so `m_level` stays the single source of truth. Alongside it: `GetPowerLevel()`, `GetMaxPowerLevel()`, `GetPauseReasons()`, `GetOvpCeiling()`, `GetPgoodFloor()`, `IsFloorFound()`, and `IsCoilEnabled()` — the last read only by the console's status dump. `RearmPowerSearch()` clears `m_floor_found` while keeping the observed bounds; it currently has **no callers**. It was written for an exit-to-automatic handover that was replaced by a full shutdown on exit, and is kept in case that handover is wanted.

**`AdjustWptPowerTransfer(step)`:**
Calls `SetPulseWidthThresholdStep(step)`, which writes:
```
voltage_mV = 400 + (step × 100)
dac_code   = voltage_mV × 65536 / (gain × VREF)
           = voltage_mV × 65536 / (2 × 2500)     ← gain is 2, see §2.2
```
to DAC CHANNEL_1 and latches via `LDAC`. Step 12 → 1600 mV → dac_code 20971. Steps above the maximum are clamped to `VoltageMaxPulseWidthThreshold_mV` by the HAL (`hal_wpt.cpp:106-109`), which is what makes the deliberately out-of-range `LEVEL_REQUEST_MAX` constant safe (it has no callers since the cold-start escalation was removed).

`WptManager::SetPowerLevel()` normalizes before recording, so `m_level` always names a real step and never the out-of-range max request.

### 6.3 Adaptive Power Control

The goal is unchanged from earlier revisions: transmit at the minimum power needed to keep the IPG's boost converter in regulation, rather than running at full power for the whole session. The mechanism is entirely different.

#### Two timers, two rates

The single 2-second timer that formerly drove both temperature and PGOOD has been split, because the two loops have opposite requirements:

| Timer | Period | Drives |
|---|---|---|
| `mFaultTimer` | 2 s | `IpgOvpMonitoring()`, then `IpgTemperatureMonitoring()` |
| `mPowerCtrlTimer` | 10 s | `PowerControlMonitoring()` |

Faults need the fast rate: the IPG holds itself in its own PAUSED state for only 5 s after a VRECT OVP event before re-enabling, so the charger has to see and react inside that window. Power steps need the slow rate: a PTH change must settle *and* propagate back through an IPG BLE advertisement before it can be evaluated, and at 2 s the loop was frequently deciding on telemetry that predated its own last change.

Every automatic path starts and stops them together through `StartIpgTemperaturePgoodMonitoringTimer()` / `StopIpgTemperaturePgoodMonitoringTimer()`. They can also be separated: `StartFaultMonitoringOnly()` starts the fault timer alone, and debug-build manual mode (§4.7) uses it. That is what makes "manual mode never titrates" structural rather than a runtime check — the power-control timer is simply never started. The single stop function still stops both.

#### The control law

`PowerControlMonitoring()` evaluates four rules:

| Observation | Meaning | Action |
|---|---|---|
| `VRECT_OVPn` asserted | Too much power | Down — handled by the fault path, §6.6 |
| PGOOD = 0, no OVP | Too little power | Up one step |
| PGOOD = 1, floor not yet found | Possibly overpowered | Down one step |
| PGOOD = 1, floor found | At the minimum viable level | Hold |

The loop starts from the level already in force: wherever the cold-start ramp stopped, or step 1 when the IPG was found in `StateScan`. The first cycle with real telemetry only marks the loop initialized and waits one more cycle. Until 2026-09-17 that cycle set step 7, a jump of up to six steps that is now avoided for the same reason as the ramp (§4.5). Because the error is correctly signed in every case, there is no reset-and-restart path, and every correction is a single 100 mV step.

Three guards run before any rule is evaluated:

```cpp
if (m_pause_reasons != 0)          return;   // fault path owns the level
if (m_blank_cycles) { m_blank_cycles--; return; }
if (adv_count == m_last_adv_count) return;   // stale telemetry, or cold start
```

The first is what makes PGOOD interpretable at all. Because the control loop bails out whenever any fault is asserted, every PGOOD = 0 it actually observes has no fault behind it — so it unambiguously means "too little power," and stepping up is correct. Faults only ever step down, and only from the 2 s path. See §6.6 for why this separation is necessary rather than merely tidy.

The third guard also cleanly gates the loop off during cold start, since the advertisement count stays at the session baseline recorded by `ResetPowerControl()` until the IPG answers. (Before 2026-09-17 the baseline was 0, so in every session after the first the previous session's last advertisement looked fresh.)

#### Floor, ceiling, and the empty window

The loop remembers both bounds it discovers:

- `m_pgood_floor` — the highest level observed to be insufficient for PGOOD
- `m_ovp_ceiling` — the lowest level observed to trip an IPG OVP fault

The ceiling is not optional bookkeeping. Without it, the "PGOOD is low, add power" rule walks straight back into the level that just faulted the IPG, and the two controllers oscillate indefinitely.

At very close coupling the ceiling can sit *at or below* the floor — no power level satisfies the IPG without faulting it. `IsPowerWindowEmpty()` detects this (`m_pgood_floor + 1 >= m_ovp_ceiling`), and the loop then clamps to `m_ovp_ceiling - 1`, sets `m_floor_found`, stops searching, and logs at ERROR. Undervoltage charging is slow but stable; ping-ponging between a faulting level and an insufficient one delivers nothing at all.

#### Debounce and ratcheting

`PGOOD_LOW_CONFIRM = 2` requires two consecutive low readings before stepping up, rejecting single-sample dropouts at the cost of one extra cycle on a real insufficiency.

Once the floor is found the level only ratchets **up**, so the loop does not hunt for the rest of the session. The one event that re-arms the downward search is a thermal pause — a thermal trip is direct evidence that the settled level delivers more power than this coupling needs, which is exactly when re-hunting is worth the effort.

#### Timing expectations

The loop now usually starts low and climbs: each step up needs two PGOOD = 0 cycles, so about 20 s per step (e.g. step 1 → 5 in about 80 s). The first confirmed insufficiency sets `m_floor_found`, so once PGOOD rises the loop holds there — the lowest viable level, reached from below. If the start level already gives PGOOD = 1, the loop descends at 10 s per step instead until PGOOD drops. A short bench test may never reach steady state; that is not a malfunction.

**Key constants:**

```cpp
COLD_START_LEVEL          = 1    // of 0..12 — reset level and cold-start ramp start
PGOOD_LOW_CONFIRM         = 2    // consecutive PGOOD=0 cycles before stepping up
BLANK_CYCLES_AFTER_FAULT  = 1    // control cycles skipped after a fault resume
MIN_POWER_LEVEL           = 0
MAX_VOLTAGE_STEP          = 12   // maximum DAC step (from the HAL)
```

### 6.4 Battery Charged Handling — Race Condition Avoidance

When the IPG reports all batteries full (§7), the application layer sends `BATTERY_CHARGED` to the system port. `StateCharge::Exit()` then sends `WPT_POWER_OFF` and `STOP_SCANNING` through the normal port path.

`StateCharging::DispatchEvent` receives `WPT_BATTERY_CHARGED` but deliberately does **not** send `WPT_POWER_OFF` directly. Doing so would race with the `SlowChargeAndScan → Charge` transition: multiple `DEVICE_FOUND` events can be queued while `STOP_SCANNING` is still pending, and a second `WPT_BATTERY_CHARGED` would disable WPT after `StateCharge::Entry()` has already re-enabled it via `WPT_POWER_ON`. Routing all shutdown through the application layer's `StateCharge::Exit()` avoids this.

**Scanning is stopped the same way (2026-09-17).** `ProcessNewBleData()` used to send `STOP_SCANNING` itself, in every application state. Only `StateCharge` acts on `BATTERY_CHARGED`; `StateScan` and `StateSlowChargeAndScan` ignore it. A drained IPG's first advertisement arrives in `StateSlowChargeAndScan` — and read as "charged" (§7) — so the scan was stopped, `BLE_DEVICE_FOUND` then moved the app into `StateCharge` with the coil on, and because `StopScanning()` also stops the scan timeout timer, `StateCharge`'s `BLE_SCAN_TIMEOUT` restart never ran. The coil stayed on at step 7 with no telemetry for the rest of the session (`Power control skipped, no new IPG advertisement since last step` every 10 s, IPG temperature frozen). Now only `StateCharge::Exit()` stops scanning. See §8.8.

### 6.5 IPG Temperature Monitoring

This loop acts on the **IPG's** temperature, broadcast over BLE — not the charger's own coil NTC, which has no control logic at all (§11). `IpgTemperatureMonitoring()` runs on the 2-second fault timer. It reads `GET_THERM_REF`, `GET_THERM_OUT`, and `GET_THERM_OFST` from the BLE advertisement and calculates IPG temperature using the same 104AP-2 NTC lookup table used by the IPG firmware:

| Temperature | Resistance |
|---|---|
| 20°C | 126,400 Ω |
| 25°C | 100,000 Ω |
| 30°C | 79,590 Ω |
| 40°C | 51,320 Ω |
| 50°C | 33,790 Ω |

**Thermal actions:**

| Condition | Action |
|---|---|
| Reading implausible (see below) | Log at WARNING with the raw values; **no decision** — not paused stays running, paused stays paused. The dwell keeps counting |
| temp ≥ 41 °C (`IPG_TEMP_THRESHOLD_PAUSE`), not already paused | `WPT_FAULT_PAUSE(PAUSE_THERMAL)` — coil output stops, monitoring continues |
| Paused, dwell < 30 s | Hold — no resume regardless of temperature |
| Paused, dwell ≥ 30 s, temp > 39 °C (`IPG_TEMP_THRESHOLD_RESUME`) | Hold — keep waiting |
| Paused, dwell ≥ 30 s **and** temp ≤ 39 °C | `WPT_FAULT_RESUME(PAUSE_THERMAL)` — coil re-enabled |
| Paused, temp > 39 °C, **no new advertisement since the pause** | Blind retry after 30 / 60 / 120 / 240 s — see below |

The dwell is counted in fault-timer ticks (`THERMAL_PAUSE_MIN_TICKS = 15` × 2 s). Both conditions are required: the dwell alone would allow re-enabling into an implant still sitting at the limit, producing a power-burst cycle rather than a controlled hold, while the threshold alone gave no guaranteed cool-down time.

**Two changes from the previous design worth noting:**

*No application-layer involvement.* The old three-tier scheme (41 °C → `TURN_OFF`, 39 °C → `WPT_POWER_OFF`, 36 °C → `WPT_POWER_ON`) sent the charger out of `StateCharge` entirely on the top tier, into a state whose only exit is a physical button press. Worse, `WPT_POWER_OFF` routed through `DisableWpt()`, which stopped the very timer that drives this function — so once paused, temperature was never re-sampled and the resume branch was unreachable dead code. Thermal faults now stay inside the WPT service layer and never touch the application state machine.

*Resume does not reset the power level.* An earlier revision called `ResetPgoodMonitoringStateMachine()` on thermal resume. Under the current design that would jump the level back to its starting point on every recovery, producing 30-second power bursts at the thermal limit. Instead the level is preserved and `m_floor_found` is cleared, re-arming the downward search (§6.3) — the trip is treated as evidence to search lower, not as a reason to start over.

**Plausibility check (2026-09-10).** The IPG packs each thermistor voltage as `mV / 10` in one byte (IPG `app_mode_ble_active.c:137-139`). THERM_REF is clamped to 255 above 2550 mV; THERM_OUT and THERM_OFST are **not** clamped, so an OUT of 2560 mV or more wraps to 0–104 (0–1040 mV). BLE viewers display such a reading as "n/a". Fed to the calculation, a wrapped OUT gives `out − ofst < 0`, a negative resistance, the table's hot end — 50 °C — and a thermal pause from a single advertisement. `IsThermReadingPlausible()` rejects, before any temperature is computed:

| Rejected when | Why |
|---|-----|
| any of ref / out / ofst = 0 | A wrapped byte, or the IPG's thermistor circuit unpowered |
| out ≤ `THERM_OUT_WRAP_MAX_MV` (1040 mV) | A wrapped OUT. The IPG MCU (STM32U585) cannot read above VREF+ ≤ 3.6 V, so a wrapped OUT always decodes to at most 3600 − 2560 = 1040 mV. This bound holds whatever OFST is. A genuine OUT this low would need the thermistor below ~10 kΩ (~85–90 °C at the design OFST of ~0.8 V), unreachable without an earlier reading tripping at 41 °C |
| out ≤ ofst | No voltage across the thermistor |
| out ≥ ref | No current through the 49.9 kΩ sense resistor. Also catches OUT at 2550–2559 mV, which encodes as 255 — the same byte as the clamped REF |

Because every wrap is caught by construction, no debounce is needed: a single *plausible* reading at or above 41 °C still pauses immediately.

**Limitation — the charger reads low while REF is clamped.** On the board where this was diagnosed THERM_REF reads exactly 2550 in every advertisement, and a wrapped OUT (≥ 2560 mV) proves the real REF is higher. The charger therefore underestimates the sense-resistor drop, overestimates the resistance (≈ 1.2 MΩ) and reads **cold** — the "20.00 C" in normal logs is the table's cold-end clamp, not a measurement. An accepted reading is a lower bound on the true temperature: a ≥ 41 °C reading is always genuine, but a real overtemperature may go unseen. The IPG's own 42 °C gate uses the full 16-bit mV values and is unaffected; it is the effective thermal limit until the IPG encoding is fixed (§11).

**Blind thermal retry — coil-powered IPG (2026-09-17).** Below ~3.2 V the IPG has no usable battery and runs directly from the rectified coil voltage. A thermal pause turns the coil off, the IPG shuts down, and no new advertisement can ever arrive; the stored reading is the one that caused the pause, so the resume branch above was unreachable and the charger sat paused until a button press (seen on hardware: 48.47 °C, then 0 advertisements). The 48 °C reading is treated as genuine throughout.

"The IPG is dark" is decided from the advertisement counter, not the battery voltage (the last BattB is itself stale): `m_thermal_pause_adv_count` is recorded when the pause starts, and an unchanged count means nothing has been heard since. An IPG running on its battery keeps advertising while paused, never takes this path, and resumes only on a real ≤ 39 °C reading as before.

| Step | Action |
|---|---|
| Paused, dark, dwell ≥ `THERMAL_BLIND_RETRY_BASE_TICKS << m_thermal_retry_count` (30, 60, 120, 240 s) | Step down one level (unless the last retry failed for lack of an advertisement), clear `m_floor_found`, set `m_blank_cycles`, start a probe, `WPT_FAULT_RESUME(PAUSE_THERMAL)`. Logs `IPG silent for N ticks in thermal pause, blind retry k/4 at level L` |
| Probe running, no new advertisement | The stale reading is ignored — it would otherwise re-pause on the next tick |
| Probe running, no advertisement within 20 s (`THERMAL_PROBE_TIMEOUT_TICKS`) | Failed (`no advertisement`): the level was too low to boot the IPG. Re-pause and queue one step **up**, never above `m_thermal_trip_level` (the level that first tripped) |
| Probe running, first fresh plausible reading **> 39 °C** | Failed (`still hot`): re-pause. The retry skipped the cool-down check, so the first real reading must meet the *resume* threshold, not just stay under 41 °C |
| Probe running, first fresh reading ≤ 39 °C | `Blind thermal retry confirmed`; retry count reset; charging continues and the power loop takes over |
| Probe running, fresh reading implausible | Keep waiting for the next advertisement, same 20 s bound |
| Paused, dark, `m_thermal_retry_count` = 4 (`THERMAL_BLIND_RETRY_MAX`) | `IPG silent after 4 blind thermal retries, ending charge session`; sends `WPT_SCAN_TIMEOUT` → `StateCharging` powers off, `StateCharge` → `StateWait` |

The coil is on only for the few seconds a drained IPG needs to boot and advertise (~1 s after cold start in the 2026-09-17 logs) before a hot reading re-pauses it, and the doubling back-off bounds the heating duty cycle over the minutes an implant takes to cool. The helper is `FailThermalProbe()`; all probe state is cleared in `ResetPowerControl()`. Hardware-tested 2026-09-17 (thresholds temporarily lowered to force pauses, IPG removed to force the give-up path, healthy-battery IPG unaffected).

**In debug-build manual mode (§4.7)** the temperature is still computed and logged every 2 s. Crossing 41 °C logs `[MANUAL] WARN thermal: … (ignored)` but sends no `WPT_FAULT_PAUSE`. The IPG's own thermal gate at 42 °C is independent of the charger and still applies.

### 6.6 OVP Handling — and why PGOOD alone is ambiguous

This is the single most important interaction between the two firmwares, and the charger did not participate in it at all before 2026-09-03.

**The mechanism.** On any OVP fault — `VRECT_OVP`, or a per-battery `CHGx_OVP_ERR` — the IPG sets `VCHG_DISABLE` and drops both `CHGx_EN` (`app_mode_wpt.c:285-295`). `VCHG_DISABLE` turns off the VCHG converter, and `VCHG_PGOOD` is that converter's own power-good pin, sampled directly into MSD bit 2 (`app_mode_ble_active.c:154`).

**Therefore an OVP pause drives PGOOD to 0.** PGOOD = 0 means either *too little power* or *too much power*, and those require opposite corrections. A controller that reads PGOOD without also reading OVP cannot tell them apart.

The pre-2026-09 charger assumed the first reading and increased power, which raised VRECT further and held the fault asserted. That produced a limit cycle matching the long-observed "collapse" symptom exactly: ramp up → PGOOD = 1 → VRECT near the OVP threshold → trips seconds later → PGOOD = 0 → old state machine resets to minimum power → VRECT collapses → OVP clears → IPG resumes → ramp up → repeat.

**The IPG was written expecting the charger to close this loop.** From `app_mode_wpt.c:291-292`, on the 5 s `WPT_OVP_PAUSE_HOLD_MS` hold:

> *"Hold in PAUSED for OVP events — gives the charger 2–3 BLE advertisement cycles to see VRECT_OVP and reduce coil power before the IPG re-enables and re-triggers the fault."*

**Charger-side handling** (`IpgOvpMonitoring()`, 2 s fault timer):

```cpp
// Raw active-low bits: 1 = OK, 0 = asserted. See the warning in §5.3.
const bool vrect_ovp = (p.GET_VRECT_OVP == 0);     // acts: pause, ceiling, step-down
const bool chg1_ovp  = (p.GET_CHG1_OVP_ERR == 0);  // logged on change only
const bool chg2_ovp  = (p.GET_CHG2_OVP_ERR == 0);  // logged on change only
```

| Step | Action |
|---|---|
| New advertisement, `VRECT_OVPn` = 0 | `m_ovp_ceiling = min(ceiling, fault_level)`, then `WPT_FAULT_PAUSE(PAUSE_OVP)` |
| New advertisement, a `CHGx_OVP_ERRn` changed | Log it — WARNING on assert, INFO on clear, with level and PGOOD. Coil unaffected |
| Same advertisement as last tick | Ignored — only fresh telemetry can report a new fault |
| Dwell < 10 s (`OVP_PAUSE_MIN_TICKS = 5`) | Hold |
| Dwell ≥ 10 s, no new advertisement since the pause | IPG dark (coil-powered): stored `VRECT_OVPn` is stale — log `IPG silent … in OVP pause, treating fault as cleared` and take the resume row below |
| Dwell ≥ 10 s, `VRECT_OVPn` still 0 | Hold, log at WARNING |
| Dwell ≥ 10 s, `VRECT_OVPn` cleared | Step level down one, set `m_blank_cycles`, `WPT_FAULT_RESUME(PAUSE_OVP)` |

**The bits are different kinds of fault** (IPG Gen2 schematic, sheets 5 and 6):

| Bit | Circuit | What it measures | Charger response |
|-----|---|---|---|
| `VRECT_OVPn` | FET U507B gated by VRECT/17 (R510 1.6 MΩ / R512 100 kΩ), drain pulled up to DVDD by R514 1 MΩ. Not gated by `VRECT_MON_EN` | Rectifier over-voltage — caused by too much coil power | Pause, **set ceiling**, step down on resume |
| `CHG1_OVP_ERRn`, `CHG2_OVP_ERRn` | TLV4021 U601 / U603 on VBAT1CHG / VBAT2CHG (trips at 4.277 V) driving FET U613B / U615B; the same comparator output opens U612A / U614A, disconnecting that battery in hardware | Battery-node over-voltage — not a function of PTH level | **Logged on change only** — no pause, no ceiling, no step-down |

**Why the battery OVP flags are log-only (2026-09-10).** The LTC4065 regulates its own 4.2 V float regardless of input power, so no PTH level can clear a genuine battery OVP — and the hardware has already disconnected that battery. The comparator is powered from +VCHG_RAIL while its output pull-up (R612 for battery B) goes to VBATxCHG, so its output is not guaranteed while that rail is collapsed — which is exactly the PGOOD = 0 condition at low power, and during every IPG pause. If the IPG's own converter shutdown leaves the coil's energy nowhere to go, VRECT rises and `VRECT_OVPn` brings the charger in through the rectifier path. Before 2026-09-10 a `CHG2_OVP_ERRn` reading paused the coil for at least 10 s and set the ceiling at whatever level was in force; since the ceiling never rises within a session, one such reading could cap power, or force the "no viable power level" clamp, for the rest of the session. Each log line carries PGOOD: a flag that only ever asserts with PGOOD = 0 points at the rail collapse rather than a real over-voltage.

**Attribution — which level a fault is charged to.** IPG telemetry lags the PTH level by up to ~3 s: the IPG samples its pins once a second, and the fault timer reads the latest advertisement every 2 s. A fault is therefore charged to `fault_level`, the highest level applied during the current or previous fault tick (`m_level_max_this_tick` / `m_level_max_last_tick`, fed by `SetPowerLevel()`), not to the level in force when it is read. Before 2026-09-10 it was charged to the level at read time, so a step down taken just before the read — the closed loop's first cycle pulling cold-start maximum (12) back to 7, or a manual `-` after an OVP warning — pinned the ceiling on a level that never faulted. Erring high is self-correcting (the step below re-trips and lowers the ceiling); erring low is not.

**Freshness.** A fault is acted on only when it arrives in a new advertisement (`m_ovp_last_adv_count`, deliberately not reset between sessions). Previously the same advertisement was re-evaluated every tick, so in manual mode — where nothing pauses — one stale OVP reading was re-charged to each new level as it was selected.

Both battery flags are reported only when they change, so a flag stuck asserted produces one line per session rather than one per advertisement; `ResetPowerControl()` clears the logged state so the next session reports it again. (The IPG itself still pauses its converter on both: its battery-present qualifier is inert because `WPT_BATT_ABSENT_THRESHOLD_MV` has been `0` since IPG commit `8e41480`, 2026-05-22, and its resume condition ignores `CHGx_OVP_ERRn`.)

**Logging.** Every OVP log prints the raw bits under their active-low names — `VRECT_OVPn=0` is a fault. The pre-2026-09-10 fault line printed normalized booleans (`vrect=1` meant fault) alongside raw-bit dumps elsewhere that use the opposite sense.

**Why the blanking cycle exists.** When the IPG re-enables, its VCHG rail needs a moment to recover, so for one or two samples PGOOD reads 0 while OVP has already cleared. That is precisely the "add power" condition, and acting on it would undo the back-off and re-trip the fault immediately. `BLANK_CYCLES_AFTER_FAULT` makes the power loop skip a cycle after any fault resume.

**Coil-powered IPG (2026-09-17).** A drained IPG goes dark when the coil stops, so the last advertisement — the one reporting the fault — was re-read forever and the pause never ended. `m_ovp_pause_adv_count` is recorded at pause; if it is unchanged after the 10 s dwell, the charger resumes one step down through the normal back-off path. The recorded ceiling keeps the power loop from climbing back into the fault. OVP carries no heating risk, so there is no back-off schedule or retry limit here (compare §6.5).

**Timing note.** The charger's 10 s pause is longer than the IPG's own 5 s hold, so the IPG re-enables first. This is safe: the charger's coil is off throughout its pause, VRECT is at zero, and `VRECT_OVPn` is therefore guaranteed clear by the time the charger resumes (one step lower after a rectifier OVP). It is more conservative than the handshake strictly requires — the IPG's stated expectation is a *power reduction*, not a coil shutdown — at the cost of ~10 s of charging per trip.

**In debug-build manual mode (§4.7)** OVP is still detected and a rectifier OVP still records `m_ovp_ceiling`, but the charger neither pauses nor steps down; it logs `[MANUAL] WARN ovp: VRECT_OVPn=0 at level …, charged to …, ceiling …, ignored` instead. The IPG's own response is unaffected — it still sets `VCHG_DISABLE`, so PGOOD still drops. That is why manual mode prints the raw IPG fault bits, including `CHG1_OVP_ERRn` and `CHG2_OVP_ERRn`, on every fault tick: it is the only way to tell an IPG protecting itself from a command that did not take effect.

---

## 7. Charging Completion Detection

`ProcessNewBleData()` in `app_state_machine.cpp` is called each time a fresh IPG advertisement arrives. It reads `CHG1_STATUS`, `CHG2_STATUS`, `VCHG_PGOOD` and both battery voltages (§5.3):

```cpp
BATTERY_FULL_MV    = 4100;   // LTC4065 float is 4.2 V; advertisement resolution 100 mV
BATTERY_PRESENT_MV = 1000;   // below this the channel has no battery

battX_measured = (battX_mV >= BATTERY_PRESENT_MV);
battX_done     = (CHGx_STATUS == 1) && (battX_mV >= BATTERY_FULL_MV);

all_done = pgood
        && (battA_measured || battB_measured)
        && (!battA_measured || battA_done)
        && (!battB_measured || battB_done);

if (all_done)
    → WptPort::WPT_BATTERY_CHARGED     (no-op in StateCharging — see §6.4)
    → SystemPort::BATTERY_CHARGED      (acted on only in StateCharge)
else
    → WptPort::WPT_BATTERY_CHARGING
```

Both log lines carry `CHG1`, `CHG2`, `PGOOD`, `BattA` and `BattB`. The still-charging branch sends `WPT_BATTERY_CHARGING` on the **WPT** port, not a system event — there is no `BATTERY_CHARGING` in `SystemPort::Event_e`. The completion branch no longer sends `STOP_SCANNING` (§6.4).

**Why the voltage is required (2026-09-17).** `CHGx_STATUS = 1` only means the LTC4065's `nCHRG` pin is floating. Observed on hardware:

| Readings | Meaning |
|---|---|
| CHG = 0, PGOOD = 1 | Charging (every normal session) |
| CHG = 1, PGOOD = 0 | Charger IC unpowered — CHG1 *and* CHG2 read 1 whenever PGOOD is 0 |
| CHG1 = 1, CHG2 = 1, PGOOD = 1, BattB = 2.5–2.8 V | Deeply discharged battery (probably LTC4065 trickle/precharge — not confirmed on the IPG side) |

The old rule (all CHG = 1 and PGOOD = 1) called the third row "charged". Requiring every present battery to read ≥ 4.1 V separates it from a real full battery. A channel below 1 V is treated as absent: the current IPG has no battery A, and BattA reads 0–200 mV (a plain `!= 0` test would have counted it as a battery that never fills, so the session would never end on its own). If no channel reads a present battery — e.g. the first advertisement after boot, which reported 0 mV — nothing is concluded and charging continues; the LTC4065 terminates its own charge (C/10 cutoff) and the IPG has its own thermal protection.

The charger firmware never instructs the LTC4065 charger ICs directly; they handle their own termination and autonomous re-charge.

---

## 8. Change History

### 8.1 — 2026-05 baseline

| File | Summary of changes |
|---|---|
| `src/application_layer/state_machine/state_charge.h` | Added `#include "svc_wpt_manager.h"` and `WptManager &mWptManager` private member |
| `src/application_layer/state_machine/state_charge.cpp` | `Entry()` now unconditionally sends `WPT_POWER_ON` and calls `StartIpgTemperaturePgoodMonitoringTimer()`; `BLE_SCAN_TIMEOUT` restarts scanning instead of exiting the state |
| `src/application_layer/state_machine/state_slow_charge_and_scan.cpp` | Scan timeout changed to `SCAN_TIMEOUT_SLOW_CHARGE_MS` (30 s); `WPT_POWER_OFF` not sent on `BLE_DEVICE_FOUND` (WPT left enabled for `StateCharge::Entry()` to take over); PGOOD monitoring timer started on device found; `PMC_POWER_ON` added to `Entry()` to enable 5V VCC rail; `PMC_POWER_OFF` added to `BLE_SCAN_TIMEOUT` and `WPT_SCAN_TIMEOUT` cases |
| `src/service_layer/ble/svc_ble_manager.h` | `SCAN_TIMEOUT_MS` changed from 2,000 to 10,000 ms; `SCAN_TIMEOUT_SLOW_CHARGE_MS` (30,000 ms) added; `CARSS_COMPANY_ID` changed from `0xFFFF` to `0xF0F0` |
| `src/service_layer/ble/svc_ble_manager.cpp` | Advertisement parser updated to new IPG MSD format (thermistors as uint8 × 10 mV, GPIO bits packed in single byte, battery voltages from msd[1]/msd[2]) |
| `src/service_layer/wpt/state_machine/svc_wpt_state_charging.cpp` | `WPT_SLOW_CHARGE` case added (clamped DAC to step 0 — superseded, see §8.3); `WPT_BATTERY_CHARGED` made a deliberate no-op (shutdown routed through app layer to avoid race) |

| Constant | Old value | New value | Reason |
|---|---|---|---|
| `SCAN_TIMEOUT_MS` | 2,000 ms | 10,000 ms | More time for the IPG to respond between advertising intervals |
| `SCAN_TIMEOUT_SLOW_CHARGE_MS` | (new) | 30,000 ms | IPG needs ~10–20 s to boot from off state via WPT |
| `CARSS_COMPANY_ID` | `0xFFFF` | `0xF0F0` | Match production IPG firmware company ID |

### 8.2 — 2026-08 thermal pause auto-resume

Charging paused at 41 °C but never resumed. Every overtemp trip sent `WPT_POWER_OFF` → `DisableWpt()`, which stopped the monitoring timer that drives `IpgTemperatureMonitoring()` — so temperature was never re-sampled and the resume branch was unreachable. The 41 °C path also sent `SystemPort::TURN_OFF`, dropping the application state machine to `StateWait`, which recovers only by button press.

Fixed by decoupling "stop delivering power" from "stop monitoring": dedicated pause/resume events that toggle only the coil driver, handled without any state transition. Thresholds were simplified from three tiers (41/39/36) to a single hysteresis band (41/39). Superseded in structure by §8.3, but the decoupling principle carries forward unchanged. The commit (`0ed080a`) also checked in a build artifact, `Firmware/hornet-wpt-charger_Debug_260804.hex`.

### 8.3 — 2026-09-03 bidirectional OVP-aware power control

Addresses two field failures: a powered-off IPG never waking at minimum coil power, and the PGOOD "collapse" limit cycle described in §6.6.

| File | Summary of changes |
|---|---|
| `src/service_layer/wpt/svc_wpt_manager.h` / `.cpp` | Monitoring timer split into `mFaultTimer` (2 s) and `mPowerCtrlTimer` (10 s); `PgoodState` machine and `IpgPgoodMonitoring()` replaced by the rule-based `PowerControlMonitoring()`; `IpgOvpMonitoring()` added; pause-reason bitmask with `PauseWpt()`/`ResumeWpt()` replacing `PauseWptForThermal()`/`ResumeWptFromThermal()`; `EnableWpt()` now honors the pause mask; `DisableWpt()` calls `ResetPowerControl()`; floor/ceiling bounds and empty-window detection added; `StartColdStartEscalation()` added; 30 s thermal dwell added |
| `src/service_layer/ble/svc_ble_manager.h` / `.cpp` | `mAdvertisementCounter` and `GetAdvertisementCount()` added for telemetry validity and freshness; `SCAN_TIMEOUT_SLOW_CHARGE_MS` shortened |
| `src/service_layer/wpt/svc_wpt_port.h` | `WPT_THERMAL_PAUSE`/`WPT_THERMAL_RESUME` renamed to `WPT_FAULT_PAUSE`/`WPT_FAULT_RESUME` at the same values, now carrying a `PauseReason_e` in `optDataAddress` |
| `src/service_layer/wpt/state_machine/svc_wpt_state_charging.cpp` | Fault cases forward the reason; `WPT_SLOW_CHARGE` now starts cold-start escalation instead of clamping to step 0 |
| `src/service_layer/wpt/state_machine/svc_wpt_state_slow_charge.cpp` | Same fault-case changes, mirrored |

| Constant | Old value | New value | Reason |
|---|---|---|---|
| `TEMP_PGODD_MONITOR_PERIOD_MS` | 2,000 ms | *(split)* | One rate could not serve both loops |
| `FAULT_MONITOR_PERIOD_MS` | (new) | 2,000 ms | The IPG holds its OVP pause only 5 s |
| `POWER_CTRL_PERIOD_MS` | (new) | 10,000 ms | A power step must settle and propagate through a BLE advertisement |
| `SCAN_TIMEOUT_SLOW_CHARGE_MS` | 30,000 ms | 10,000 ms | Cold start now uses high power, so the attempt either works quickly or not at all |
| `IPG_TEMP_THRESHOLD_HIGH/MEDIUM/LOW` | 41 / 39 / 36 °C | *(removed)* | Replaced by a single pause/resume band |
| `IPG_TEMP_THRESHOLD_PAUSE` / `_RESUME` | (new) | 41 / 39 °C | Single hysteresis band |
| `STABILITY_THRESHOLD`, `MAX_FINE_TUNE_STEPS`, `MAX_COUNT_TOGGLING` | 10 / 2 / 3 | *(removed)* | Sized for the deleted state machine and the 2 s cadence |

Two logging-only commits also landed on this branch. `2eb194b` (before the above) made `IpgTemperatureMonitoring()` log the IPG temperature to two decimal places and added a raw `GET_THERM_REF/OUT/OFST` line. `68d90a0` (after it) renamed the resistance log line in `CalculateTemperatureFromBle()` from "IPG thermal resistance" to "IPG thermistor resistance". Neither changes behaviour.

### 8.4 — 2026-09-09 manual/debug control mode over RTT

Adds a bench-test mode so the control loop of §8.3 can be validated against a hand-driven
ground truth. Off by default and absent from a production binary: everything is gated on
`WPT_MANUAL_DEBUG_MODE` in `src/service_layer/debug/svc_debug_config.h`, and a debug build
still boots and runs the normal automatic loop until the operator presses `m` over RTT.

Manual mode is an **application-layer state**, `StateManual`, not a flag that carves
exceptions out of the automatic states. The first cut was flag-based and failed on
hardware in three ways, all traceable to that choice:

1. It never raised VCC_EN, so the console drove `PIN_WPT_EN` into an unpowered LTC4125.
   The 5 V rail is owned solely by the PMC state machine (`PmcStateEnable::Entry/Exit`),
   and only `StateCharge::Entry()` and `StateSlowChargeAndScan::Entry()` ever request it.
2. `DebugConsole::StartCoil()` sent `WPT_FAULT_RESUME` before `WPT_POWER_ON`, but WPT
   `StateIdle` drops the former, so a set `PAUSE_MANUAL` could never be cleared.
3. It gated `StateCharge` but not `StateSlowChargeAndScan`, whose `BLE_SCAN_TIMEOUT`
   handler is the only one in the codebase that sends `WPT_POWER_OFF` **and**
   `PMC_POWER_OFF` **and** `ChangeState(pStateWait)` — killing power ~10 s in.

The third is the instructive one: the bug was a *missing exception*, which is the failure
mode a flag-based design invites and a state-based one cannot have. Behaviour that must
not happen in manual mode is now expressed as the absence of a case in
`StateManual::DispatchEvent`, and behaviour that must happen is `Entry()`/`Exit()`.

Seven conditional gates collapsed to two:

| Original gate | Now |
|---|---|
| `StateCharge` `BATTERY_CHARGED` | never a transition in `StateManual` — handled only to re-arm scanning |
| `StateCharge` `WPT_SCAN_TIMEOUT` | no such case |
| `StateSlowChargeAndScan` power-off (the missed one) | not in that state |
| `PowerControlMonitoring` | `mPowerCtrlTimer` is never started |
| `StartColdStartRamp` / `ColdStartRampStep` (were `StartColdStartEscalation` / `ColdStartEscalate`) | never started in manual mode; a ramp left running by the previous state is cancelled on entry (`EnterManualIdle()`) |
| `IpgTemperatureMonitoring` warn-only | **kept** — the monitor must run and report |
| `IpgOvpMonitoring` warn-only | **kept** — same |

The two survivors are genuinely conditional: manual mode changes whether those monitors
*act*, not whether they *run*.

**This does not make the system unprotected.** The IPG runs its own thermal gate at 42 °C
and its own OVP shutdown, neither of which the charger can disable (§6.6). That is why
manual mode prints the IPG's raw fault bits on every 2 s fault tick — without that line,
an IPG protecting itself is indistinguishable from a command that never took effect. A
dead-man timeout pauses the coil after 10 minutes with no keystroke, covering the one risk
the IPG's own gate does not: a bench rig with no IPG present.

| File | Summary of changes |
|---|---|
| `src/service_layer/debug/svc_debug_config.h` | New. `WPT_MANUAL_DEBUG_MODE` (default 0), poll period, dead-man timeout |
| `src/service_layer/debug/svc_debug_console.{h,cpp}` | New. 100 ms RTT poll timer, single-keystroke handling, status dump, dead-man timer, `IsManual()`; `OnManualEntered()`/`OnManualExited()` so `StateManual` owns the manual flag |
| `src/application_layer/state_machine/state_manual.{h,cpp}` | New. `Entry()` raises VCC_EN, starts scanning and sends `WPT_MANUAL_IDLE`; ignores Button 1; re-arms scanning after `BATTERY_CHARGED`; `Exit()` stops the coil, scanning and the rail |
| `src/application_layer/app_port.h` | `MANUAL_TAKEOVER = 0x12`. `SystemPort::ExecuteEvent` dispatches straight to the state machine and never indexes `mEventCallback`, so `MAX_EVENT_ENUM_LENGTH` does not constrain it as it does on the BLE and WPT ports |
| `src/application_layer/state_machine/app_state_machine.{h,cpp}` | `StateManual` registered in `StatePointers` and the constructor |
| `state_wait.cpp`, `state_scan.cpp`, `state_slow_charge_and_scan.cpp`, `state_charge.cpp` | One `MANUAL_TAKEOVER` case each → `ChangeState(pStateManual)` |
| `src/service_layer/wpt/svc_wpt_manager.{h,cpp}` | `PAUSE_MANUAL` in `PauseReason_e`; `StartFaultMonitoringOnly()`; `EnterManualIdle()`; `m_coil_enabled` + `IsCoilEnabled()`; `RearmPowerSearch()` (currently unused, §6.2); warn-only thermal/OVP paths; IPG-bit logging in `FaultMonitoring()`; accessors for the status dump |
| `src/service_layer/wpt/svc_wpt_port.h` | `WPT_MANUAL_IDLE = 0x11` (debug builds) |
| `svc_wpt_state_idle.cpp`, `svc_wpt_state_charging.cpp`, `svc_wpt_state_slow_charge.cpp` | `WPT_MANUAL_IDLE` case → `EnterManualIdle()`; the two active states also → `StateIdle` (debug builds) |
| `src/service_layer/wpt/state_machine/svc_wpt_state_slow_charge.cpp` | **Bug fix, independent of debug mode:** added the missing `WPT_ADJUST_POWER` case. Power adjustments arriving in this state were previously discarded and the DAC kept its prior value |
| `src/hal_layer/hal_wpt.h` | `StepToMillivolts()` so a PTH step can be reported in volts without duplicating the range constants |
| `src/project/project/hornet-wpt-charger.emProject` | New `debug` folder, include directory, and `state_manual.cpp` |

Design notes worth preserving:

- **One new WPT port event, deliberately.** `MAX_EVENT_ENUM_LENGTH` is 20 and `WptPort::Event_e`
  already reached `0x10`. PTH changes reuse `WPT_ADJUST_POWER`; coil stop/start reuses
  `WPT_FAULT_PAUSE`/`WPT_FAULT_RESUME` with `PAUSE_MANUAL`. The one addition,
  `WPT_MANUAL_IDLE` (0x11), exists because entry has to be ordered after the previous
  state's queued WPT events (§4.7).
- **`StateManual::Entry()` drives the WPT side to `StateIdle` rather than inheriting it.**
  The coil is off because of where that state machine is, not because of a pause bit
  something else might clear. `s` is what moves it to `StateCharging`.
- **Command ordering in `StartCoil()` is load-bearing**: `WPT_POWER_ON` →
  `WPT_FAULT_RESUME` → `WPT_ADJUST_POWER`. The latter two are dropped by `StateIdle`.
- **A manual stop is a pause, not `WPT_POWER_OFF`.** Power-off transitions to `StateIdle`
  and calls `DisableWpt()` → `ResetPowerControl()`, discarding the state being observed.
  `x` therefore leaves VCC_EN up, so only `WPT_ENn` moves between stop and start.
- **`StateManual::Exit()` must send `PMC_POWER_OFF` itself** — `StateCharge::Exit()` does
  not, which is why leaving `StateCharge` normally parks VCC_EN high.
- **`IsCoilEnabled()` is not `GetPauseReasons() == 0`.** In `StateIdle` the mask is zero and
  the coil is off, which is exactly where manual mode idles before `s`.

| Key | Action | Key | Action |
|-----|---|-----|---|
| `m` / `n` | enter / exit manual mode | `s` / `x` | coil start / stop |
| `+` / `-` | step PTH up / down | `0`-`9`, `a`, `b`, `c` | set PTH step 0-12 |
| `?` | status dump | `h` | help |

Single keystrokes were chosen so commands fit the existing 16-byte RTT down-buffer; no
`sdk_config.h` change is required.

**Latent trap, not currently live:** `EnableWpt()` starts `mStatusTimeoutTimer` (5 s), whose
callback sends `WPT_SCAN_TIMEOUT` if `GetStat() == 1`, and `StateCharging` answers that with
`WPT_POWER_OFF`. In manual mode that would be a silent kill. It cannot fire today because
`Wpt_LTC4125::GetStat()` is stubbed to `return 0` (§11). If HSD-285 is ever resolved and
`GetStat()` implemented, this path must be revisited.

**Status (2026-09-10).** Documenting the `StateManual` design turned up four defects by inspection: three entry paths that did not meet the "coil off, monitoring on" contract, and a stale console flag after leaving with Button 1. The same day, manual mode was changed to override every operational state explicitly — stopping any charge in progress and idling until `s` — with entry routed through `WPT_MANUAL_IDLE`, Button 1 disabled, and the flag owned by the state (§4.7). Both flag states compile clean across all 53 first-party sources. Not yet run on hardware; the only hardware run so far was the flag-based first cut described above.

### 8.5 — 2026-09-10 OVP polarity audit and false-ceiling fix

**Trigger.** Bench logs showed an OVP-based ceiling being recorded while the IPG board showed no over-voltage.

**Polarity: correct, no change needed.** Every active-low bit is compared `== 0` for "asserted", and the IPG packs raw pin levels (§5.3).

**Causes found and fixed** (all in `IpgOvpMonitoring()`, §6.6):

| # | Defect | Fix |
|---|---|-----|
| 1 | `CHG2_OVP_ERRn` — a battery-node comparator — paused the coil, set the PTH ceiling and earned a step down | `CHG1_OVP_ERRn` and `CHG2_OVP_ERRn` are logged on change only; `VRECT_OVPn` alone pauses, sets the ceiling and steps down |
| 2 | Faults charged to the level in force when read, though telemetry lags ~3 s | Charged to the highest level applied over the last two fault ticks |
| 3 | The same advertisement re-evaluated every tick | Faults acted on only from a new advertisement |
| 4 | Fault log printed normalized booleans (`vrect=1` = fault) beside raw-bit dumps | All logs print raw bits under `…n` names; `[MANUAL] IPG bits` now includes both battery OVP bits (drops `CHG1_STATUS` for NRF_LOG's six-argument limit) |

| File | Change |
|---|---|
| `src/service_layer/wpt/svc_wpt_manager.{h,cpp}` | `IpgOvpMonitoring()` reworked; `RecordOvpCeiling()`; `m_ovp_last_adv_count`, `m_chg1_ovp_logged` / `m_chg2_ovp_logged`, `m_level_max_this_tick` / `m_level_max_last_tick`; `SetPowerLevel()` feeds the window, `ResetPowerControl()` resets it |
| `src/application_layer/state_machine/app_state_machine.cpp` | Per-advertisement dump labels the raw bits with their polarity |
| `src/service_layer/debug/svc_debug_console.cpp` | `LogIpgBits()` prints `CHG1_OVP_ERRn` and `CHG2_OVP_ERRn` |

**Battery OVP flags made log-only (same day).** A first cut kept `CHG2_OVP_ERRn` as a coil pause without a ceiling. Since U612A/U614A already disconnect the battery in hardware and coil power cannot clear a genuine battery OVP, both `CHGx_OVP_ERRn` flags were then made log-only at the user's request.

**Status.** Both flag states compile clean across all 53 first-party sources. Not yet run on hardware. Scoping `CHG2.OVP_ERRn` (TP626) against +VCHG_RAIL at low PTH would confirm or rule out the rail-collapse false assert.

---

### 8.6 — 2026-09-10 IPG thermistor byte-wrap false thermal trips

**Symptom.** Occasional pauses logged as `IPG temperature 50.00 C reached pause threshold (41 C)`, each coinciding with the BLE viewer showing the IPG temperature as "n/a". Logged raw values flipped from `ref=2550 out=2500 ofst=1280` (20 °C) to `ref=2550 out=0 ofst=1390` (resistance printed as 0, 50 °C).

**Not bit loss.** Every BLE packet carries a CRC-24 and corrupted packets are discarded by the radio; the viewer and the charger independently decoded the same value, so the IPG transmitted it.

**Root cause (IPG firmware, unchanged).** `app_mode_ble_active.c:137-139` clamps THERM_REF at 2550 mV but casts THERM_OUT and THERM_OFST straight to `uint8_t`, so they wrap at 2560 mV. THERM_OUT sits around 2.50 V on this board and occasionally crosses 2.56 V.

**Fix (charger only, by decision — the IPG repo is not touched).**

| File | Change |
|---|---|
| `svc_wpt_manager.h/.cpp` | New `IsThermReadingPlausible()` and `THERM_OUT_WRAP_MAX_MV` (§6.5). `IpgTemperatureMonitoring()` calls it before computing a temperature; an implausible reading is logged and takes no pause/resume decision. The paused-dwell counter now advances before the check, so it keeps counting through rejected readings. The resistance log casts to `int32_t` (a negative float through NRF_LOG's `uint32_t` cast was undefined and printed 0) |

Pause behaviour is otherwise unchanged: one plausible reading ≥ 41 °C still pauses; resume still needs the 30 s dwell and ≤ 39 °C.

**Verification.** A host-side sweep of the rule against the IPG's packing accepted none of 14.2 M wrapped combinations (REF 2.40–3.60 V, OUT 2.55–3.60 V, OFST 0–2.55 V). Of 8,520 genuine design-range readings it rejected only 15, all with a thermistor resistance of about 10 kΩ (≈ 85 °C) — the floor's corner.

**Status.** Compiles clean in both `WPT_MANUAL_DEBUG_MODE` states. Not hardware-tested. Check: when the viewer shows "n/a", RTT should show `IPG thermistor reading implausible (…), ignored` with matching raw values and charging should continue.

### 8.7 — 2026-09-11 Cold-start escalation made optional

The jump to maximum power during cold start is now behind a build-time flag, off by default, and the white-light scan window is back at 30 s.

| File | Change |
|---|---|
| `svc_wpt_manager.h` | New `COLD_START_ESCALATION_ENABLED` (`false`). `COLD_START_ESCALATE_MS` 5,000 → 30,000 ms |
| `svc_wpt_manager.cpp` | `StartColdStartEscalation()` still sets step 7, but starts `mColdStartEscalateTimer` only when the flag is `true`; otherwise it logs `Cold start at level 7, escalation disabled` |
| `svc_ble_manager.h` | `SCAN_TIMEOUT_SLOW_CHARGE_MS` 10,000 → 30,000 ms |

Nothing else needed changing: `StartColdStartEscalation()` is the only place the timer is started, and the `Stop()` in `DisableWpt()` is harmless on a timer that never ran. `ColdStartEscalate()` and `LEVEL_REQUEST_MAX` remain for the enabled case.

With the flag off, a drained IPG gets step 7 (1100 mV) for 30 s; if it has not advertised by then, the charger returns to `StateWait`. To re-enable escalation, set the flag to `true` **and** make `COLD_START_ESCALATE_MS` shorter than `SCAN_TIMEOUT_SLOW_CHARGE_MS` (§4.5).

This also resolves the §11 note about `state_slow_charge_and_scan.cpp:29` ("a longer scan timeout"): the slow-charge window is again longer than the default, so the comment is accurate.

**Status.** Compiles clean (syntax check of all 53 first-party sources, `WPT_MANUAL_DEBUG_MODE` = 1 as currently set). Not hardware-tested.

### 8.8 — 2026-09-17 Drained-IPG charging: stuck scan, false "charged", pause deadlock

**Symptom.** With an IPG battery below 3.2 V, charging started but the charger then ignored all further advertisements (visible in a BLE viewer) and logged `Power control skipped, no new IPG advertisement since last step` every 10 s. No power or temperature control ran; the IPG temperature stayed frozen at 20.00 °C; only the IPG's own thermal gate still acted.

**Root causes.**

1. *False "charged".* A 2.5 V battery reports CHG1 = 1, CHG2 = 1, PGOOD = 1, which the completion rule accepted as full (§7).
2. *Scan stopped outside `StateCharge`.* `ProcessNewBleData()` sent `STOP_SCANNING` directly. The first advertisement from a drained IPG arrives in `StateSlowChargeAndScan`, which ignores `BATTERY_CHARGED`; the scan and its timeout timer stopped, `BLE_DEVICE_FOUND` moved the app into `StateCharge` with the coil on, and nothing restarted the scan (§6.4).
3. *Pause deadlock (found after 1–2 were fixed).* A coil-powered IPG goes dark when a thermal or OVP pause turns the coil off, so the stale reading that caused the pause is re-evaluated forever (§6.5, §6.6). Seen as a 48.47 °C thermal pause that never ended.

**Fix.**

| File | Change |
|---|---|
| `app_state_machine.cpp` | `STOP_SCANNING` removed from `ProcessNewBleData()`. Completion requires every present battery (≥ `BATTERY_PRESENT_MV` = 1000 mV) to read ≥ `BATTERY_FULL_MV` = 4100 mV with CHG = 1, plus PGOOD; no present battery → keep charging. BattA / BattB logged separately |
| `svc_wpt_manager.h/.cpp` | Blind thermal retry (`THERMAL_BLIND_RETRY_BASE_TICKS`, `THERMAL_BLIND_RETRY_MAX`, `THERMAL_PROBE_TIMEOUT_TICKS`, `FailThermalProbe()`, probe state cleared in `ResetPowerControl()`). OVP pause resumes one step down when no advertisement has arrived during the 10 s dwell |

**Status.** Hardware-tested 2026-09-17 (commit `db8b343`). Scanning continued throughout a drained-IPG session (94 advertisements, all correctly "in progress", closed loop running). Blind retry, give-up after four failures, and unchanged behaviour with a healthy battery were confirmed on the bench.

**Not done — keep-alive level during a pause.** Instead of turning the coil off, drop to a level at which the IPG stays powered with PGOOD = 0 (many such advertisements appear in the logs), so it keeps reporting temperature and the blind period disappears. The coil itself heats the implant, so this needs bench thermal measurements first.

### 8.9 — 2026-09-17 Cold-start ramp from step 1

**Reason.** Jumping straight to step 7 at cold start occasionally caused physical damage to the IPG's rectifier.

**Change.** Cold start now begins at step 1 and rises one step every 30 s until the IPG advertises or step 12 is reached (§4.5). The closed loop keeps whatever level it inherits instead of forcing step 7 (§6.3).

| File | Change |
|---|---|
| `svc_wpt_manager.h` | `COLD_START_LEVEL` 7 → 1. `COLD_START_ESCALATE_MS` and `COLD_START_ESCALATION_ENABLED` replaced by `COLD_START_STEP_MS` = 30,000. `StartColdStartEscalation()` / `ColdStartEscalate()` / `mColdStartEscalateTimer` renamed to `StartColdStartRamp()` / `ColdStartRampStep()` / `mColdStartRampTimer`. New `m_cold_start_adv_count` |
| `svc_wpt_manager.cpp` | Periodic ramp timer and step logic. `EnableWpt()` writes `m_level` to the DAC before enabling. `StartIpgTemperaturePgoodMonitoringTimer()` stops the ramp. The first control cycle no longer sets step 7. `ResetPowerControl()` records the current advertisement count instead of 0 |
| `svc_wpt_state_charging.cpp` | `WPT_SLOW_CHARGE` calls `StartColdStartRamp()` |
| `svc_ble_manager.h` | `SCAN_TIMEOUT_SLOW_CHARGE_MS` 30,000 → 390,000 ms |
| `eda_timer.cpp` | `Start(period)` / `StartFromISR(period)` convert ms to ticks with `pdMS_TO_TICKS()` |

**Latent bugs fixed along the way** (each would have undermined the ramp):

1. *Coil started at the previous session's level.* `DisableWpt()` leaves the DAC alone, and `EnableWpt()` enabled the LTC4125 before the cold-start level was written.
2. *Advertisement counter compared against 0.* The counter runs from boot. In any session after the first, `ColdStartEscalate()` always saw "advertising" and `PowerControlMonitoring()` treated the previous session's last advertisement as fresh — forcing step 7 within 10 s of cold start.
3. *Timer periods passed as ticks.* At 1024 Hz every `Start(period)` window was about 2.3 % short, which would have cut the final 30 s hold at step 12 to about 21 s.

**Status.** Syntax-checked (no errors in first-party code). Not hardware-tested.

## 9. Event Flow — Complete Happy Path

### 9.1 IPG already advertising (awake)

```
User presses button
  → OnOffButtonCallback() → SystemPort::BUTTON_PRESSED
  → App SM: StateWait → StateScan
  → StateScan::Entry(): BlePort::START_SCANNING, blue LED on
  → BleManager::StartScanning(), 10 s timer started

IPG advertisement received (company ID 0xF0F0)
  → BleManager::ParseManufacturerSpecificData()
  → BlePort::DEVICE_FOUND (from ISR)
  → App SM: StateScan → StateCharge
  → StateScan::Exit(): WptPort::WPT_POWER_ON (WPT SM: StateIdle → StateCharging), blue LED off
  → StateCharge::Entry():
      PmcPort::PMC_POWER_ON
      yellow LED on
      WptPort::WPT_POWER_ON (no-op — WPT SM already in StateCharging)
      mWptManager.StartIpgTemperaturePgoodMonitoringTimer()
  → StateCharging::Entry(): mWptManager.EnableWpt() (WPT_EN LOW, starts status timers)

Every 2 s (mFaultTimer): IpgOvpMonitoring() + IpgTemperatureMonitoring()
  → VRECT_OVPn=0:  record ovp_ceiling, WPT_FAULT_PAUSE(PAUSE_OVP)   (CHGx_OVP_ERRn: logged only)
                   after 10 s and clear: step down one, resume
  → temp ≥ 41°C:   WPT_FAULT_PAUSE(PAUSE_THERMAL)
                   after 30 s and ≤ 39°C: resume, re-arm the floor search
  (Neither leaves StateCharge — the yellow LED stays on throughout)

Every 10 s (mPowerCtrlTimer): PowerControlMonitoring()
  → skipped while any fault is pending, blanked, or telemetry is stale
  → first cycle with telemetry: keep the current level, decide next cycle
  → PGOOD=1, floor not found: step down
  → PGOOD=1, floor found:     hold
  → PGOOD=0 twice running:    step up, record pgood_floor, floor found

IPG advertisement: every present battery CHG=1 and ≥ 4.1 V, PGOOD=1 (§7)
  → ProcessNewBleData() → SystemPort::BATTERY_CHARGED
  → App SM: StateCharge → StateWait
  → StateCharge::Exit(): BlePort::STOP_SCANNING, WptPort::WPT_POWER_OFF, yellow LED off
  → green LED on
```

### 9.2 IPG powered off (slow charge path)

```
User presses button
  → StateScan::Entry(): blue LED, BLE scanning (10 s)

No IPG found — BLE_SCAN_TIMEOUT fires
  → StateScan → StateSlowChargeAndScan
  → StateSlowChargeAndScan::Entry():
      SetScanTimeout(390 s)
      BlePort::START_SCANNING
      WptPort::WPT_SLOW_CHARGE     ← cold start: LTC4125 at step 1, ramp timer started
      white LED on

Every 30 s with no advertisement
  → ColdStartRampStep(): LTC4125 one step higher (stops at step 12)

WPT powers IPG; IPG boots, starts advertising
  → BleManager receives advertisement
  → BlePort::DEVICE_FOUND
  → App SM: StateSlowChargeAndScan → StateCharge
      WPT and VCC left enabled (no WPT_POWER_OFF or PMC_POWER_OFF sent)
  → StateSlowChargeAndScan::Exit():
      SetScanTimeout(10 s) (restore default), white LED off
  → StateCharge::Entry():
      PMC_POWER_ON (no-op — PMC already in PmcStateEnable), yellow LED
      WptPort::WPT_POWER_ON       ← transitions WPT SM from any state to StateCharging
      StartIpgTemperaturePgoodMonitoringTimer()   ← also stops the ramp

First 10 s control cycle with telemetry
  → level kept where the ramp stopped; closed loop takes over one step at a time

... charging proceeds as normal ...
```

### 9.3 Manual bench control (debug builds only)

```
Debug build, board in any operational state (idle, scanning, slow charge, charging)

Operator presses 'm' over RTT
  → DebugConsole::EnterManual(): request only
  → SystemPort::MANUAL_TAKEOVER
  → App SM: <any operational state> → StateManual
      (the previous state's Exit() runs first and may queue WPT events)
  → StateManual::Entry():
      DebugConsole::OnManualEntered() ← m_manual = true
      PmcPort::PMC_POWER_ON          ← VCC_EN high; LTC4125 powered
      BlePort::START_SCANNING        ← telemetry for the warn-only monitors
      WptPort::WPT_MANUAL_IDLE       ← processed after the previous state's WPT events
      magenta LED
  → WPT task, EnterManualIdle():
      DisableWpt()                   ← coil off, timers stopped, ramp cancelled,
                                       level → step 1
      StartFaultMonitoringOnly()     ← fault timer only; no titration, no cold start
      WPT SM → StateIdle             ← coil off until 's'

Operator presses 's'
  → PmcPort::PMC_POWER_ON            (no-op — already in PmcStateEnable)
  → WptPort::WPT_POWER_ON            ← WPT SM: StateIdle → StateCharging → EnableWpt()
  → WptPort::WPT_FAULT_RESUME(PAUSE_MANUAL)
  → WptPort::WPT_ADJUST_POWER(level)
    (order matters: StateIdle would drop the last two)

'+' / '-' / '0'…'9', 'a', 'b', 'c'
  → WptManager::SetPowerLevelManual() → WPT_ADJUST_POWER → DAC CH1

'x'
  → WPT_FAULT_PAUSE(PAUSE_MANUAL)    ← coil off; VCC_EN stays up; stays in StateCharging

Every 2 s (mFaultTimer)
  → thermal / OVP thresholds evaluated, logged as [MANUAL] WARN, never acted on
  → [MANUAL] IPG bits: … printed every tick

Every 10 s with no IPG (BLE_SCAN_TIMEOUT)
  → StateManual re-sends START_SCANNING — no state change, power unaffected

10 min with no keystroke (dead-man)
  → WPT_FAULT_PAUSE(PAUSE_MANUAL) — coil off until the operator presses 's'

Button 1
  → ignored in StateManual (logged); Button 2 still resets the MCU

IPG reports battery charged
  → StateManual re-sends START_SCANNING on BATTERY_CHARGED (redundant since §8.8 —
    ProcessNewBleData() no longer stops scanning)

Operator presses 'n'
  → DebugConsole::ExitManual(): request only
  → SystemPort::TURN_OFF
  → App SM: StateManual → StateWait   (always StateWait, never the previous state)
  → StateManual::Exit(): OnManualExited() (m_manual = false), stop monitoring
                         timers, WPT_POWER_OFF, STOP_SCANNING, PMC_POWER_OFF, LED off
```

---

## 10. Constants Reference

**`svc_ble_manager.h`:**
```cpp
SCAN_INTERVAL              = 0x00A0
SCAN_WINDOW                = 0x0050
SCAN_TIMEOUT_MS            = 10000     // ms — StateScan and StateCharge
SCAN_TIMEOUT_SLOW_CHARGE_MS = 390000  // ms — StateSlowChargeAndScan; 12 ramp steps + 1 held at max
CARSS_COMPANY_ID           = 0xF0F0   // Production IPG company ID
```

**`svc_wpt_manager.h`:**
```cpp
// Timers
FAULT_MONITOR_PERIOD_MS        = 2000     // ms — temperature + OVP sampling
POWER_CTRL_PERIOD_MS           = 10000    // ms — power search step interval
COLD_START_STEP_MS             = 30000    // ms — cold-start ramp: time at each level before +1 step

// Thermal (single hysteresis band + dwell)
IPG_TEMP_THRESHOLD_PAUSE       = 41       // °C — pause at/above
IPG_TEMP_THRESHOLD_RESUME      = 39       // °C — resume at/below
THERMAL_PAUSE_MIN_TICKS        = 15       // fault ticks (× 2 s) = 30 s dwell
THERM_OUT_WRAP_MAX_MV          = 1040     // mV — THERM_OUT at/below this is a wrapped byte, rejected
THERMAL_BLIND_RETRY_BASE_TICKS = 15       // fault ticks (× 2 s) = 30 s; doubles per failed retry
THERMAL_BLIND_RETRY_MAX        = 4        // failed blind retries before the session ends
THERMAL_PROBE_TIMEOUT_TICKS    = 10       // fault ticks (× 2 s) = 20 s for a retry to see an advertisement

// OVP
OVP_PAUSE_MIN_TICKS            = 5        // fault ticks (× 2 s) = 10 s dwell

// Power search
MIN_POWER_LEVEL                = 0        // PTH step
COLD_START_LEVEL               = 1        // PTH step — reset level and cold-start ramp start
LEVEL_INVALID                  = 0xFF     // sentinel: no bound observed yet
LEVEL_REQUEST_MAX              = 0xFE     // out of range on purpose; HAL clamps (currently unused)
PGOOD_LOW_CONFIRM              = 2        // consecutive PGOOD=0 cycles before stepping up
BLANK_CYCLES_AFTER_FAULT       = 1        // control cycles skipped after a fault resume
```

**`app_state_machine.cpp`** (local to `ProcessNewBleData()`):
```cpp
BATTERY_FULL_MV            = 4100      // mV — a present battery must reach this to count as full
BATTERY_PRESENT_MV         = 1000      // mV — a channel below this has no battery
```

**`hal_wpt.h`:**
```cpp
VoltageMinPulseWidthThreshold_mV  = 400
VoltageMaxPulseWidthThreshold_mV  = 1600
VoltageStepPulseWidthThreshold_mV = 100
MAX_VOLTAGE_STEP_PULSE_WIDTH      = 12
NTC_R0                            = 5000     // Ω — local NTC at 25°C
NTC_BETA                          = 3480
```

**`svc_debug_config.h`** (debug console — see §4.7):
```cpp
WPT_MANUAL_DEBUG_MODE      = 0         // 1 = compile the console and StateManual in
WPT_MANUAL_POLL_PERIOD_MS  = 100       // ms — RTT keystroke poll
WPT_MANUAL_DEADMAN_MS      = 600000    // ms — pause the coil after 10 min idle; 0 disables
```

---
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

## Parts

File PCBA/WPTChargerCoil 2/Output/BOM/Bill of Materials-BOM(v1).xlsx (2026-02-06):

Designator | Name | Description | Quantity | Manufacturer Part Number | Manufacturer
L200 | 760308100110 | 1 Coil, 2 Layer 24µH Wireless Charging Coil Transmitter 70mOhm | 1 | 760308100110 | Wurth
NTC200 | NTCS0603E3502FLT | NTC SMD 0603, 5KOHM, 1%, B25/85 | 1 | NTCS0603E3502FLT | Vishay Dale
J200, J201 | U.FL-R-SMT-1(10) | RF Connector, 1 Contact(s), Male, Board Mount, Surface Mount Terminal, Receptacle | 2 | U.FL-R-SMT-1(10) | Hirose

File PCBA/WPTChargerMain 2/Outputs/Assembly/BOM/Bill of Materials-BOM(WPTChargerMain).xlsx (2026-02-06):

Designator | Name | Description | Quantity | Manufacturer Part Number | Manufacturer
R503, R611 | RCS08050000Z0EA | 0 Ohms Jumper Chip Resistor 0805 (2012 Metric) Automotive AEC-Q200, Pulse Withstanding Thick Film | 2 | RCS08050000Z0EA | Vishay Dale
C301 | GRM155R61C473KA01D | 0.047 µF ±10% 16V Ceramic Capacitor X5R 0402 (1005 Metric) | 1 | GRM155R61C473KA01D | Murata Electronics
C404, C408 | C3216C0G2A104J160AC | 0.1 µF ±5% 100V Ceramic Capacitor C0G, NP0 1206 (3216 Metric) | 2 | C3216C0G2A104J160AC | TDK Corporation
C310, C311, C318, C319, C320, C323, C324, C325, C326 | GRM155R61H104KE14D | 0.1 µF ±10% 50V Ceramic Capacitor X5R 0402 (1005 Metric) | 9 | GRM155R61H104KE14D | Murata Electronics
C401, C605 | GRM155R6YA105KE11D | 1 µF ±10% 35V Ceramic Capacitor X5R 0402 (1005 Metric) | 2 | GRM155R6YA105KE11D | Murata
C300, C309 | GRM155R61H105KE05D | 1 µF ±10% 50V Ceramic Capacitor X5R 0402 (1005 Metric) | 2 | GRM155R61H105KE05D | Murata Electronics
C316 | GCM1555C1H1R0JA16D | 1 pF ±5% 50V Ceramic Capacitor C0G, NP0 0402 (1005 Metric) | 1 | GCM1555C1H1R0JA16D | Murata Electronics
C317 | GJM1555C1H1R2WB01J | 1.2 pF ±0.05pF 50V Ceramic Capacitor C0G, NP0 0402 (1005 Metric) | 1 | GJM1555C1H1R2WB01J | Murata Electronics
C606 | GRM155R61C225KE44D | 2.2 µF ±10% 16V Ceramic Capacitor X5R 0402 (1005 Metric) | 1 | GRM155R61C225KE44D | Murata
L303 | LQG15HS2N2B02D | 2.2 nH Unshielded Multilayer Inductor 900 mA 90mOhm Max 0402 (1005 Metric) | 1 | LQG15HS2N2B02D | Murata Electronics
R607 | CRCW04023K24FKED | 3.24 kOhms ±1% 0.063W, 1/16W Chip Resistor 0402 (1005 Metric) Automotive AEC-Q200 Thick Film | 1 | CRCW04023K24FKED | Vishay Dale
R616 | CRCW04023M30FKED | 3.3 MOhms ±1% 0.063W, 1/16W Chip Resistor 0402 (1005 Metric) Automotive AEC-Q200 Thick Film | 1 | CRCW04023M30FKED | Vishay
L302 | LQG15HS4N7B02D | 4.7 nH Unshielded Multilayer Inductor 700 mA 160mOhm Max 0402 (1005 Metric) | 1 | LQG15HS4N7B02D | Murata Electronics
R408, R412 | RC0402FR-075KL | 5 kOhms ±1% 0.063W, 1/16W Chip Resistor 0402 (1005 Metric) Moisture Resistant Thick Film | 2 | RC0402FR-075KL | Yageo
U400 | LTC4125IUFD#TRPBF | 5W Autoresonant Wireless Power Transmitter PMIC 20-QFN (4x5) | 1 | LTC4125IUFD#TRPBF | Analog Devices Inc.
R600, R601 | CRCW04025K11FKEDC | 5.11 kOhms ±1% 0.063W, 1/16W Chip Resistor 0402 (1005 Metric) Thick Film | 2 | CRCW04025K11FKEDC | Vishay Dale
D603 | PESD5V5C1BLYL | 5.4V (Typ) Clamp 6.5A (8/20µs) Ipp Tvs Diode Surface Mount DFN1006-2 | 1 | PESD5V5C1BLYL | Nexperia
L301 | ASMCI-0603-100M-T | 10 µH Shielded Multilayer Inductor 50 mA 900mOhm 0603 (1608 Metric) | 1 | ASMCI-0603-100M-T | Abracon LLC
C308, C312, C313, C315 | GJM1555C1H120FB01D | 12 pF ±1% 50V Ceramic Capacitor C0G, NP0 0402 (1005 Metric) | 4 | GJM1555C1H120FB01D | Murata Electronics
R400 | WSL0603R0150FEA18 | 15 mOhms ±1% 0.2W, 1/5W Chip Resistor 0603 (1608 Metric) Automotive AEC-Q200, Current Sense, Moisture Resistant, Pulse Withstanding Metal Element | 1 | WSL0603R0150FEA18 | Vishay Dale
L300 | LQG15HS15NG02D | 15 nH Unshielded Multilayer Inductor 450 mA 320mOhm Max 0402 (1005 Metric) | 1 | LQG15HS15NG02D | Murata Electronics
U401 | DAC80504RTET | 16 Bit Digital to Analog Converter 4 16-WQFN (3x3) | 1 | DAC80504RTET | Texas Instruments
C503 | GRM188R61A226ME15D | 22 µF ±20% 10V Ceramic Capacitor X5R 0603 (1608 Metric) | 1 | GRM188R61A226ME15D | Murata
Y300 | ECS-320-10-48-CKY-TR | 32 MHz Â±10ppm Crystal 10pF 100 Ohms 4-SMD, No Lead | 1 | ECS-320-10-48-CKY-TR | ECS Inc.
Y301 | ECS-.327-9-34B-C-TR | 32.768 kHz ±10ppm Crystal 9pF 70 kOhms 2-SMD, No Lead | 1 | ECS-.327-9-34B-C-TR | ECS Inc.
C411 | GCM1555C1H360FA16D | 36 pF ±1% 50V Ceramic Capacitor C0G, NP0 0402 (1005 Metric) | 1 | GCM1555C1H360FA16D | Murata
C402, C403 | GRM21BR61A476ME15L | 47 µF ±20% 10V Ceramic Capacitor X5R 0805 (2012 Metric) | 2 | GRM21BR61A476ME15L | Murata
R312 | CRCW040247R0FKED | 47 Ohms ±1% 0.063W, 1/16W Chip Resistor 0402 (1005 Metric) Automotive AEC-Q200 Thick Film | 1 | CRCW040247R0FKED | Vishay Dale
R411 | CRCW0603100KFKEAC | 100 kOhms ±1% 0.1W, 1/10W Chip Resistor 0603 (1608 Metric) Automotive AEC-Q200 Thick Film | 1 | CRCW0603100KFKEAC | Vishay
C314 | GRM1555C1H101JA01D | 100 pF ±5% 50V Ceramic Capacitor C0G, NP0 0402 (1005 Metric) | 1 | GRM1555C1H101JA01D | Murata Electronics
R401 | RN73R1ETTP2983F50 | 298 kOhms ±1% 0.063W, 1/16W Chip Resistor 0402 (1005 Metric) Automotive AEC-Q200, Moisture Resistant Thin Film | 1 | RN73R1ETTP2983F50 | KOA Speer Electronics, Inc.
L500 | XGL4015-681MEC | 680 nH Shielded Molded Inductor 8.1 A 10.1mOhm Max 1616 (4040 Metric) | 1 | XGL4015-681MEC | Coilcraft
R501 | CRCW0402732KFKED | 732 kOhms ±1% 0.063W, 1/16W Chip Resistor 0402 (1005 Metric) Automotive AEC-Q200 Thick Film | 1 | CRCW0402732KFKED | Vishay Dale
C405 | GCM155R71E472KA37D | 4700 pF ±10% 25V Ceramic Capacitor X7R 0402 (1005 Metric) | 1 | GCM155R71E472KA37D | Murata
D300, D301, D302 | IN-PI20TAT5R5G5B | Addressable Lighting - 1 LED Discrete Red, Green, Blue (RGB) 2.0mm L x 2.0mm W | 3 | IN-PI20TAT5R5G5B | Inolux
U601 | MC34673AEPR2 | Battery Charger Li-Ion/Li-Pol 1200mA 4.2V 8-Pin UDFN T/R | 1 | MC34673AEPR2 | NXP Semiconductors
J302 | 1513430-1 | BLE 2.45 GHz SMD Antenna. | 1 | 1513430-1 | TE Connectivity
U501 | TPS61023DRLR | Boost Switching Regulator IC Positive Adjustable 2.2V 1 Output 3A SOT-563, SOT-666 | 1 | TPS61023DRLR | Texas Instruments
P300 | RDTE-4.000-3030-NS1 | Buzzers Transducer, Externally Driven Magnetic 3 V 120mA 4kHz 72dB @ 3V, 10cm Surface Mount Solder Pads | 1 | RDTE-4.000-3030-NS1 | Raltron Electronics
C400, C413, C414, C415 | GCM155R71H103KA55J | Capacitor, 0.01uF, X7R, 50V, 10%, 0402, Implant-grade | 4 | GCM155R71H103KA55J | Murata
C305, C306, C307, C406, C407, C409, C410, C500, C501, C602, C604 | GCM155R71C104KA55 | Capacitor, 0.1uF, X7R, 16V, 10%, 0402, Implant-grade | 11 | GCM155R71C104KA55 | Murata
C502 | ZRB15XR61A106ME01D | Capacitor, 10uf, X5R, 10V, 20%, 0402, Implant-grade | 1 | ZRB15XR61A106ME01D | Murata
J300 | TC2050-IDC-NL | Cbl Plug-Of-Nails 10-Pin 1.27mm | 1 | TC2050-IDC-NL | Tag-Connect LLC
C302, C303, C304, C412 | GRM155R61A334KE15D | Ceramic Capacitor, Multilayer, Ceramic, 10V, 10% +Tol, 10% -Tol, X5R, 15% TC, 0.33uF, Surface Mount, 0402 | 4 | GRM155R61A334KE15D | Murata
C600, C601, C603 | C1005X5R1A475K050BC | Ceramic Capacitor, Multilayer, Ceramic, 10V, 20% +Tol, 20% -Tol, X5R, 15% TC, 4.7uF, Surface Mount, 0402 | 3 | C1005X5R1A475K050BC | TDK
J600 | 1054500101 | CONN RCP USB3.1 TYPEC 24P SMD RA | 1 | 1054500101 | Molex
JP600 | TSW-102-25-G-S-RA | Conn Unshrouded Header HDR 2 POS 2.54mm 90 degrees Solder ST Thru-Hole | 1 | TSW-102-25-G-S-RA | Samtec
D601, D602 | PMEG3050EP,115 | Diode 30 V 5A Surface Mount SOD-128/CFP5 | 2 | PMEG3050EP,115 | Nexperia USA Inc.
D401 | BAT54LP-7 | Diode 30 V 200mA Surface Mount X1-DFN1006-2 | 1 | BAT54LP-7 | Diodes Incorporated
D303, D400 | BAS521-7 | Diode 300 V 250mA Surface Mount SOD-523 | 2 | BAS521-7 | Diodes Incorporated
R504 | CRCW0402499RFKEDHP | Fixed Resistor, Metal Glaze/thick Film, 0.2W, 499ohm, 50V, 1% +/-Tol, 100ppm/Cel, Surface Mount, 0402 | 1 | CRCW0402499RFKEDHP | Vishay Dale
U301 | NRF52840-QFAA-F-R7 | IC RF TxRx + MCU 802.15.4, Bluetooth Bluetooth v5.0, Thread, Zigbee® 2.4GHz 48-VFQFN Exposed Pad | 1 | NRF52840-QFAA-F-R7 | Nordic Semiconductor
U600 | CP2102N-A02-GQFN20R | IC USB TO UART BRIDGE QFN20 | 1 | CP2102N-A02-GQFN20R | Silicon Labs
U500 | AP7354-33W5-7 | Ldo, Fixed, 3.3V, 0.15A, -40 To 85Deg C Rohs Compliant: Yes | 1 | AP7354-33W5-7 | Diodes Inc
D604 | LTST-C191TGKT | LED, GREEN, SMD, 0603, 3.2V, 20mA | 1 | LTST-C191TGKT | Lite-On Inc.
D500 | LTST-C191KFKT | LED, ORANGE, SMD, 0603, 2V, 30mA | 1 | LTST-C191KFKT | Lite-On Inc.
T600, T601 | PMPB11R2VPX | MOSFET, technology, P-MOS, 1 Channel, Vgs th 0.9 max, 1.9 W, SMD | 2 | PMPB11R2VPX | Nexperia
M300, M400 | NVS4001NT1G | N-Channel 30 V 270mA (Ta) 330mW (Ta) Surface Mount SC-70-3 (SOT323) | 2 | NVS4001NT1G | onsemi
SW1, SW2, SW3 | PTS647SN50SMTR2LFS | Pushbutton, NO-MOM, 12V, 0.05A, SMT | 3 | PTS647SN50SMTR2LFS | C&K
R603, R604, R605, R612, R613 | CRCW04021K00FKED | Res Thick Film 0402 1K Ohm 1% 1/16W ±100ppm/°C Molded SMD Paper T/R | 5 | CRCW04021K00FKED | Vishay Dale
R602, R606, R615 | CRCW04021M00FKED | Res Thick Film 0402 1M Ohm 1% 0.063W(1/16W) ±100ppm/°C Pad SMD Automotive T/R | 3 | CRCW04021M00FKED | Vishay
R303, R304, R305, R409 | CRCW040210K0FKED | Res Thick Film 0402 10K Ohm 1% 1/16W ±100ppm/°C Molded SMD SMD Paper T/R | 4 | CRCW040210K0FKED | Vishay Dale
R300 | RC0402FR-13470RL | Res Thick Film 0402 470 Ohm 1% 1/16W ±100ppm/°C Molded SMD SMD Paper T/R | 1 | RC0402FR-13470RL | Yageo
R619 | CRCW0402200RFKEDHP | Resistor 200 1%, 0402, Non Implant-grade | 1 | CRCW0402200RFKEDHP | Vishay
R301 | PA0402-R-070RL | Resistor, 0 Ohm, 0402, Metal element, Non-Implant grade, | 1 | PA0402-R-070RL | YAGEO
R614 | CRCW04021M20FKEDC | Resistor, 1.2 M 1%, 0402 | 1 | CRCW04021M20FKEDC | Vishay
R618 | CRCW04021M50FKED | Resistor, 1.5 M 1%, 0402 | 1 | CRCW04021M50FKED | Vishay
R617 | CRCW04022M80FKED | Resistor, 2.8 M 1%, 0402 | 1 | CRCW04022M80FKED | Vishay
R402, R403, R407, R410, R502, R608, R609, R610 | ERJ-2RKF1003X | Resistor, 100k, 1%, 0402, Implant-grade | 8 | ERJ-2RKF1003X | Panasonic
R405, R406, R500 | ERJ-2GE0R00X | Resistor, Zero ohms, 40V, 40mW, 1%, 0402, Implant-grade | 3 | ERJ-2GE0R00X | Panasonic
J400, J401 | U.FL-R-SMT-1(10) | RF Connector, 1 Contact(s), Male, Board Mount, Surface Mount Terminal, Receptacle | 2 | U.FL-R-SMT-1(10) | Hirose
D600 | IP4220CZ6F | TVS DIODE 5.5VWM 6TSOP | 1 | IP4220CZ6F | Nexperia
U300, U302 | 2N7001TQDCKRQ1 | Voltage Level Translator, Automotive 1-bit dual-supply buffered voltage signal translator | 2 | 2N7001TQDCKRQ1 | Texas Instruments

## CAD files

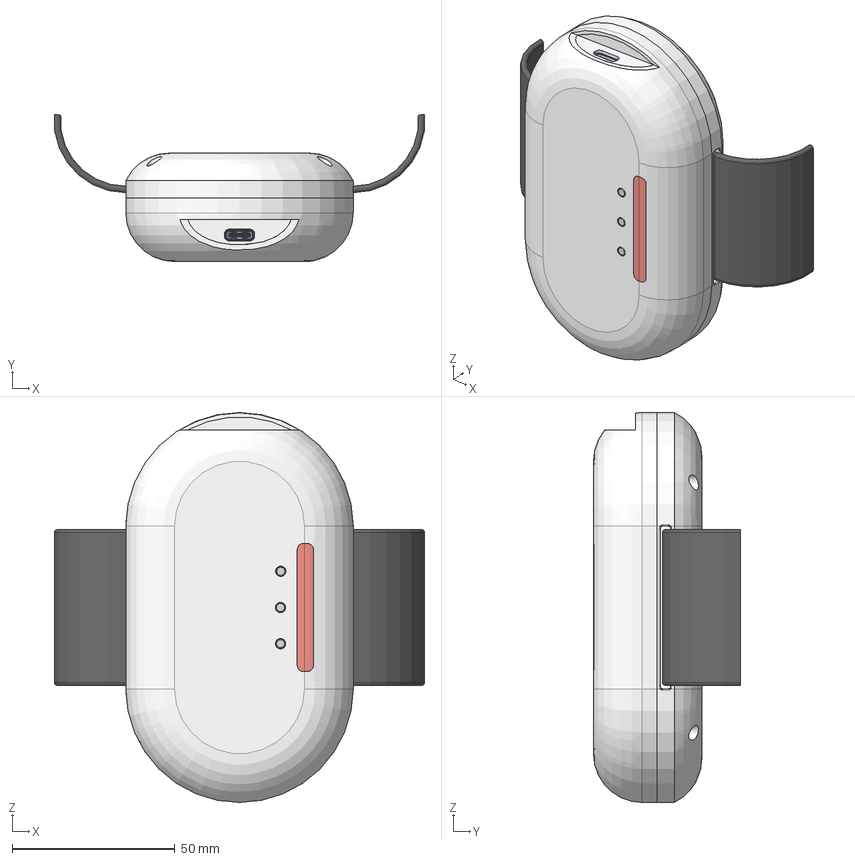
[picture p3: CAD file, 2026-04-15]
Enclosure/Hornet Charger- Casing_Rev C.step
114.0 x 45.3 x 120.0 mm
Mid Body_23 x 17
Mark_6 x 17
ECS-.327-9-34B-C-TR
User Library-QFN48
LQG15HS4N7B02D x 3
ASMCI-0603-100M-T
PESD5V5C1BLYL
Thermal Shape
pins
logo
BODY-SOT
Thermal Shape_1
PTS647SN50SMTR2LFS x 3
Mid Body_20 x 7
Mark_3 x 7
Mid Body_17 x 2
Mark x 2
Mid Body_22 x 9
Mark_5 x 9
Mid Body_18 x 4
Mark_1 x 4
Mid Body_19
Mark_2
Mid Body_21
Mark_4
RDTE-4.000-3030-NS1
Leader x 3
Leader_1 x 3
SOT-323-3_2P2X1P35_ONS x 2
Coilcraft-XAL4020
TSW-102-25-G-S-RA_body
T-1S6-15-TSW-1-25-2-RA-S
105450-0101--3DModel-STEP-56544
U.FL-R-SMT-1 x 2
Hirose Logo adjastable x 2
IC_BODY
IC_LEG x 6
circle
Nexperia
DIODE_X1-DFN1006-2_P6X1_DIO
DIO_521-7_DIO x 2
Pins_1 x 3
Bottom Section - Base
Bateria
Acrylic Bar
Top Section V2 - Base
Top Section V2 - standoffs
NTCS0603E3
turns
place holder
U.FL-R-SMT-1_1 x 2
Hirose Logo adjastable_1 x 2
Middle Section
Cinta

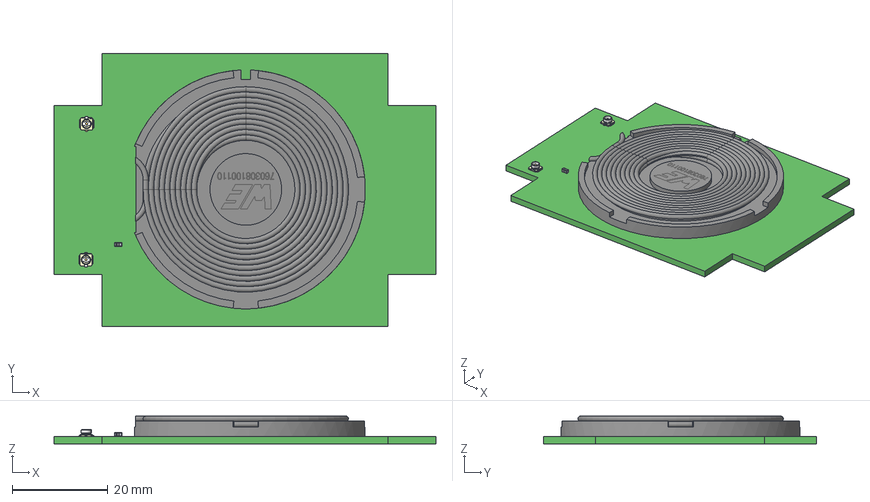
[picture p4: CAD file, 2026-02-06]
PCBA/WPTChargerCoil 2/Output/ExportSTEP/WPTChargerCoil(v1).step
79.9 x 57.1 x 5.85 mm
NTCS0603E3
turns
place holder
U.FL-R-SMT-1 x 2
Hirose Logo adjastable x 2

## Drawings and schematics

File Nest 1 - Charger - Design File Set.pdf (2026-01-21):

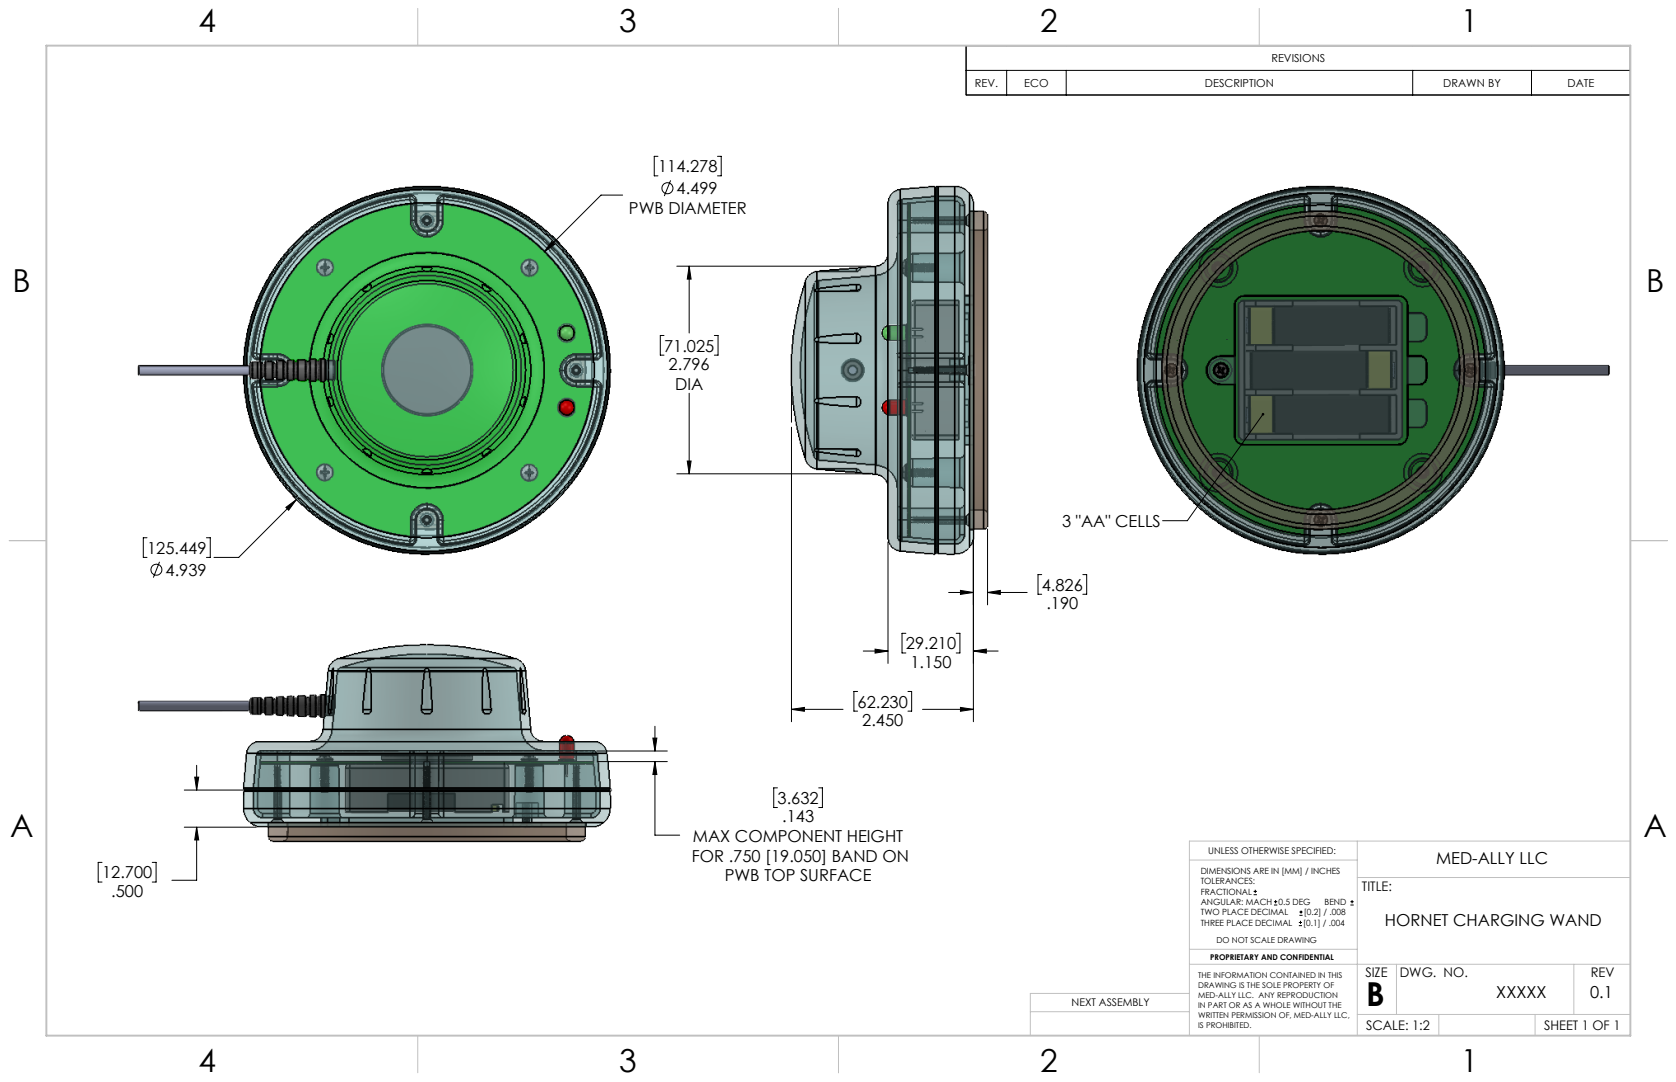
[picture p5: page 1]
PWB DIAMETER; PWB TOP SURFACE; 3 "AA" CELLS; TWO PLACE DECIMAL; NEXT ASSEMBLY

REVISIONS

REV. | ECO | DESCRIPTION | DRAWN BY | DATE

MAX COMPONENT HEIGHT
FOR .750 [19.050] BAND ON

UNLESS OTHERWISE SPECIFIED:
DIMENSIONS ARE IN [MM] / INCHES
TOLERANCES:
FRACTIONAL
ANGULAR: MACH 0.5 DEG BEND
THREE PLACE DECIMAL [0.1] / .004
DO NOT SCALE DRAWING
PROPRIETARY AND CONFIDENTIAL

MED-ALLY LLC

TITLE:
HORNET CHARGING WAND

THE INFORMATION CONTAINED IN THIS DRAWING IS THE SOLE PROPERTY OF MED-ALLY LLC. ANY REPRODUCTION IN PART OR AS A WHOLE WITHOUT THE WRITTEN PERMISSION OF, MED-ALLY LLC, IS PROHIBITED. | SIZE B | DWG. NO. XXXXX | REV 0.1

SCALE: 1:2 | | SHEET 1 OF 1

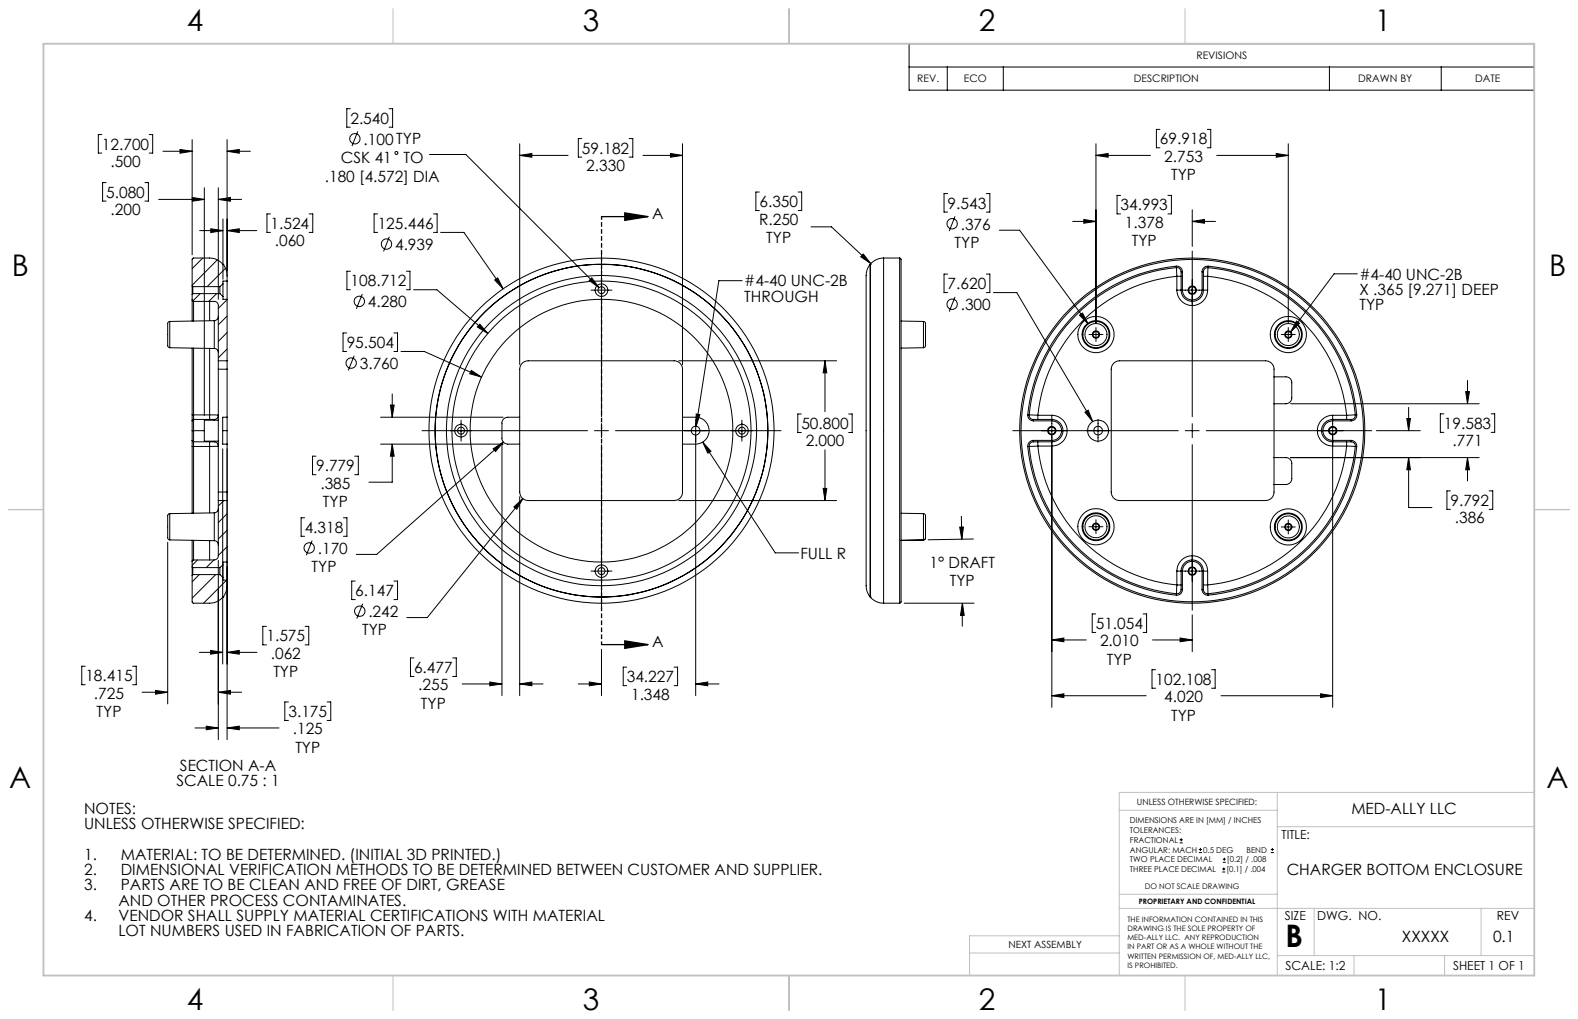
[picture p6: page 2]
.100 TYP CSK 41 TO .180 [4.572] DIA; FULL R; #4-40 UNC-2B; SECTION A-A SCALE 0.75 : 1; 1° DRAFT; #4-40 UNC-2B X .365 [9.271] DEEP; CHARGER BOTTOM ENCLOSURE; DWG. NO.; REV; TWO PLACE DECIMAL

NOTES:
UNLESS OTHERWISE SPECIFIED:
1. MATERIAL: TO BE DETERMINED. (INITIAL 3D PRINTED.)
2. DIMENSIONAL VERIFICATION METHODS TO BE DETERMINED BETWEEN CUSTOMER AND SUPPLIER.
3. PARTS ARE TO BE CLEAN AND FREE OF DIRT, GREASE
AND OTHER PROCESS CONTAMINATES.
4. VENDOR SHALL SUPPLY MATERIAL CERTIFICATIONS WITH MATERIAL
LOT NUMBERS USED IN FABRICATION OF PARTS.

DIMENSIONS ARE IN [MM] / INCHES
TOLERANCES:
FRACTIONAL
ANGULAR: MACH 0.5 DEG BEND
THREE PLACE DECIMAL [0.1] / .004
DO NOT SCALE DRAWING
PROPRIETARY AND CONFIDENTIAL
THE INFORMATION CONTAINED IN THIS
DRAWING IS THE SOLE PROPERTY OF

MED-ALLY LLC

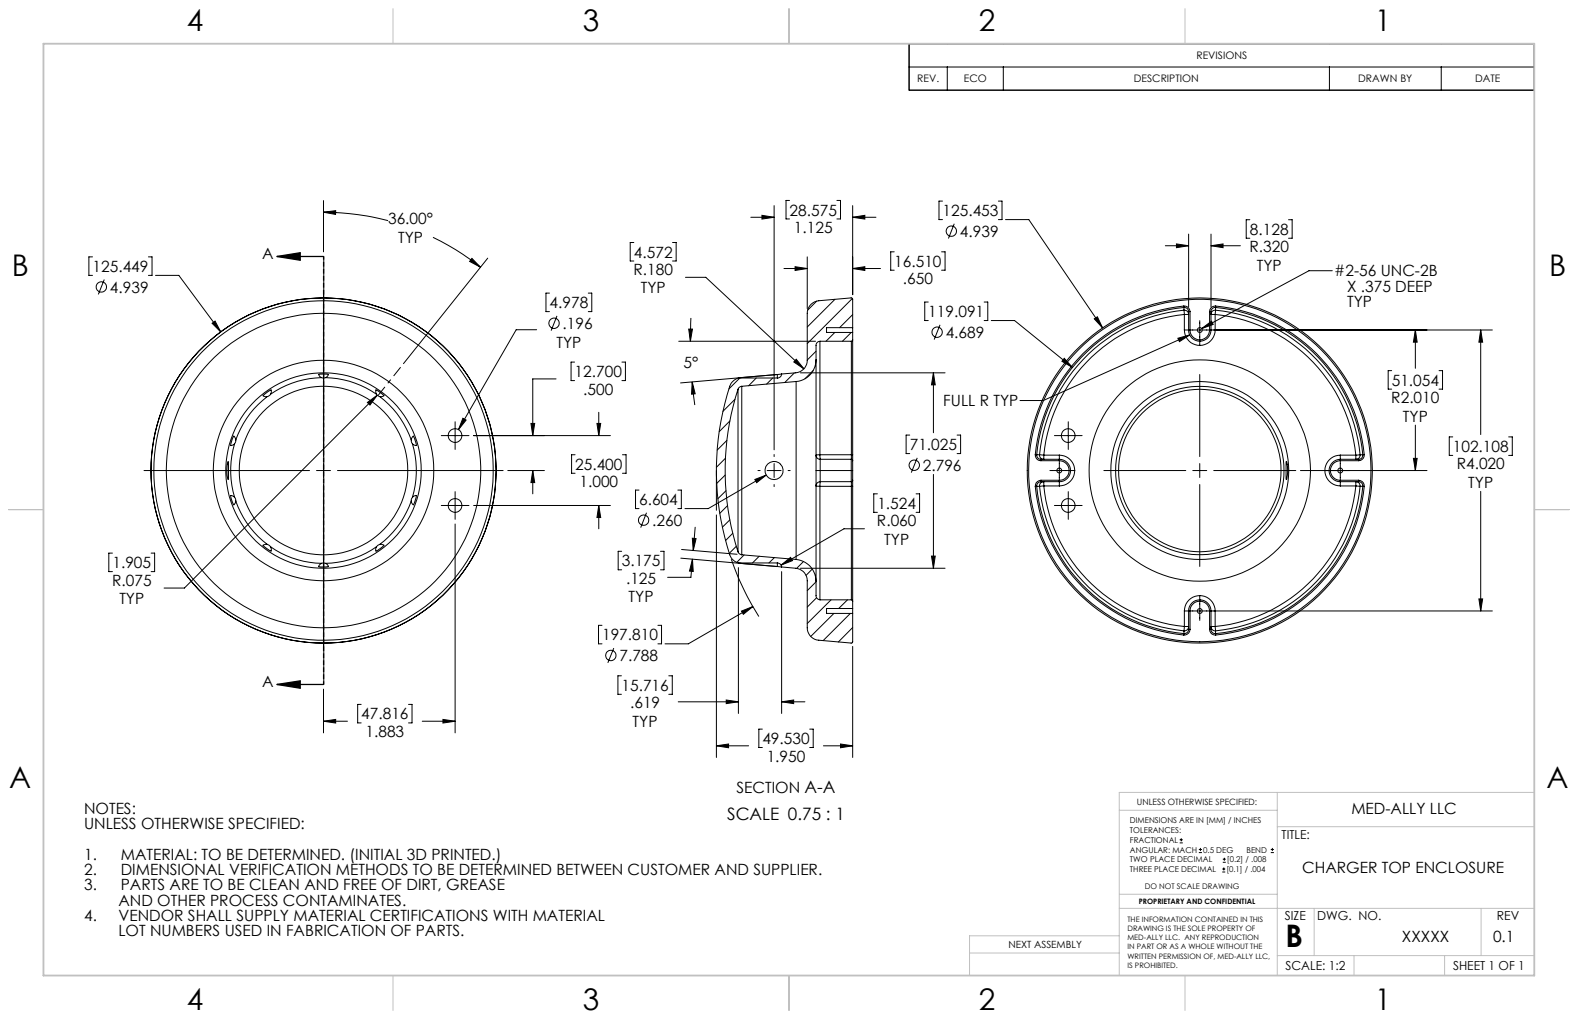
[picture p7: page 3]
SECTION A-A SCALE 0.75 : 1; FULL R TYP; #2-56 UNC-2B X .375 DEEP; CHARGER TOP ENCLOSURE; DWG. NO.; REV; TWO PLACE DECIMAL

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

MED-ALLY LLC

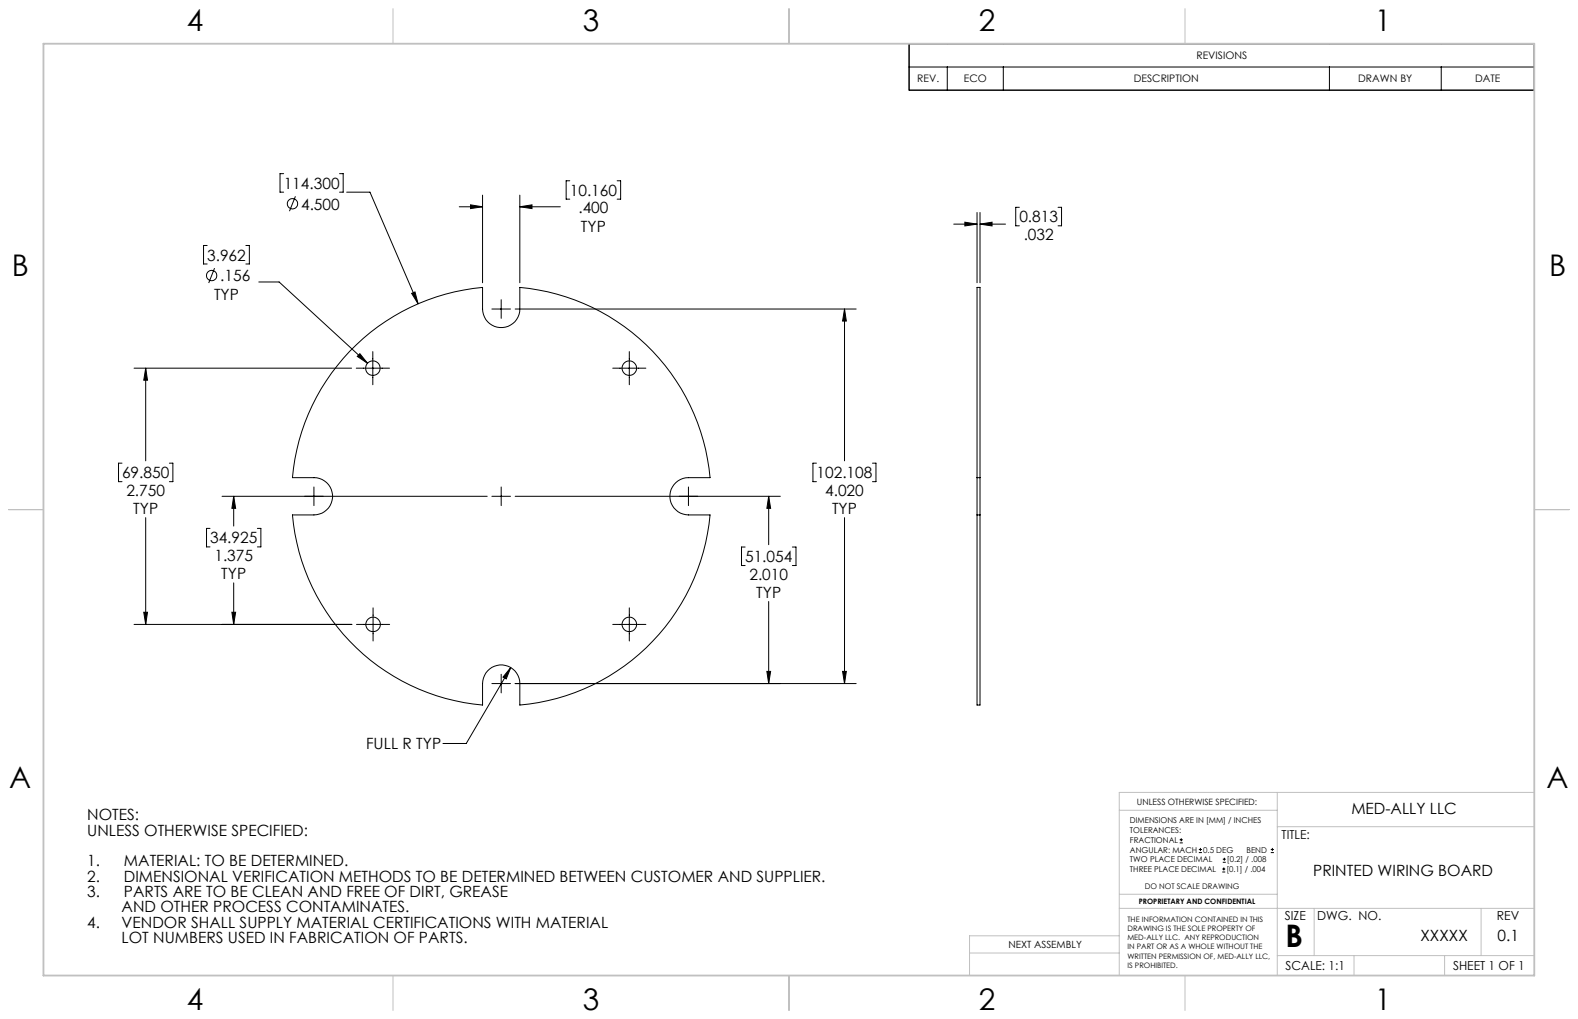
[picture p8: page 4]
FULL R TYP; PRINTED WIRING BOARD; DWG. NO.; REV; TWO PLACE DECIMAL

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

MED-ALLY LLC

NOTES:
1. MATERIAL: TO BE DETERMINED.
2. DIMENSIONAL VERIFICATION METHODS TO BE DETERMINED BETWEEN CUSTOMER AND SUPPLIER.
3. PARTS ARE TO BE CLEAN AND FREE OF DIRT, GREASE
AND OTHER PROCESS CONTAMINATES.
4. VENDOR SHALL SUPPLY MATERIAL CERTIFICATIONS WITH MATERIAL
LOT NUMBERS USED IN FABRICATION OF PARTS.

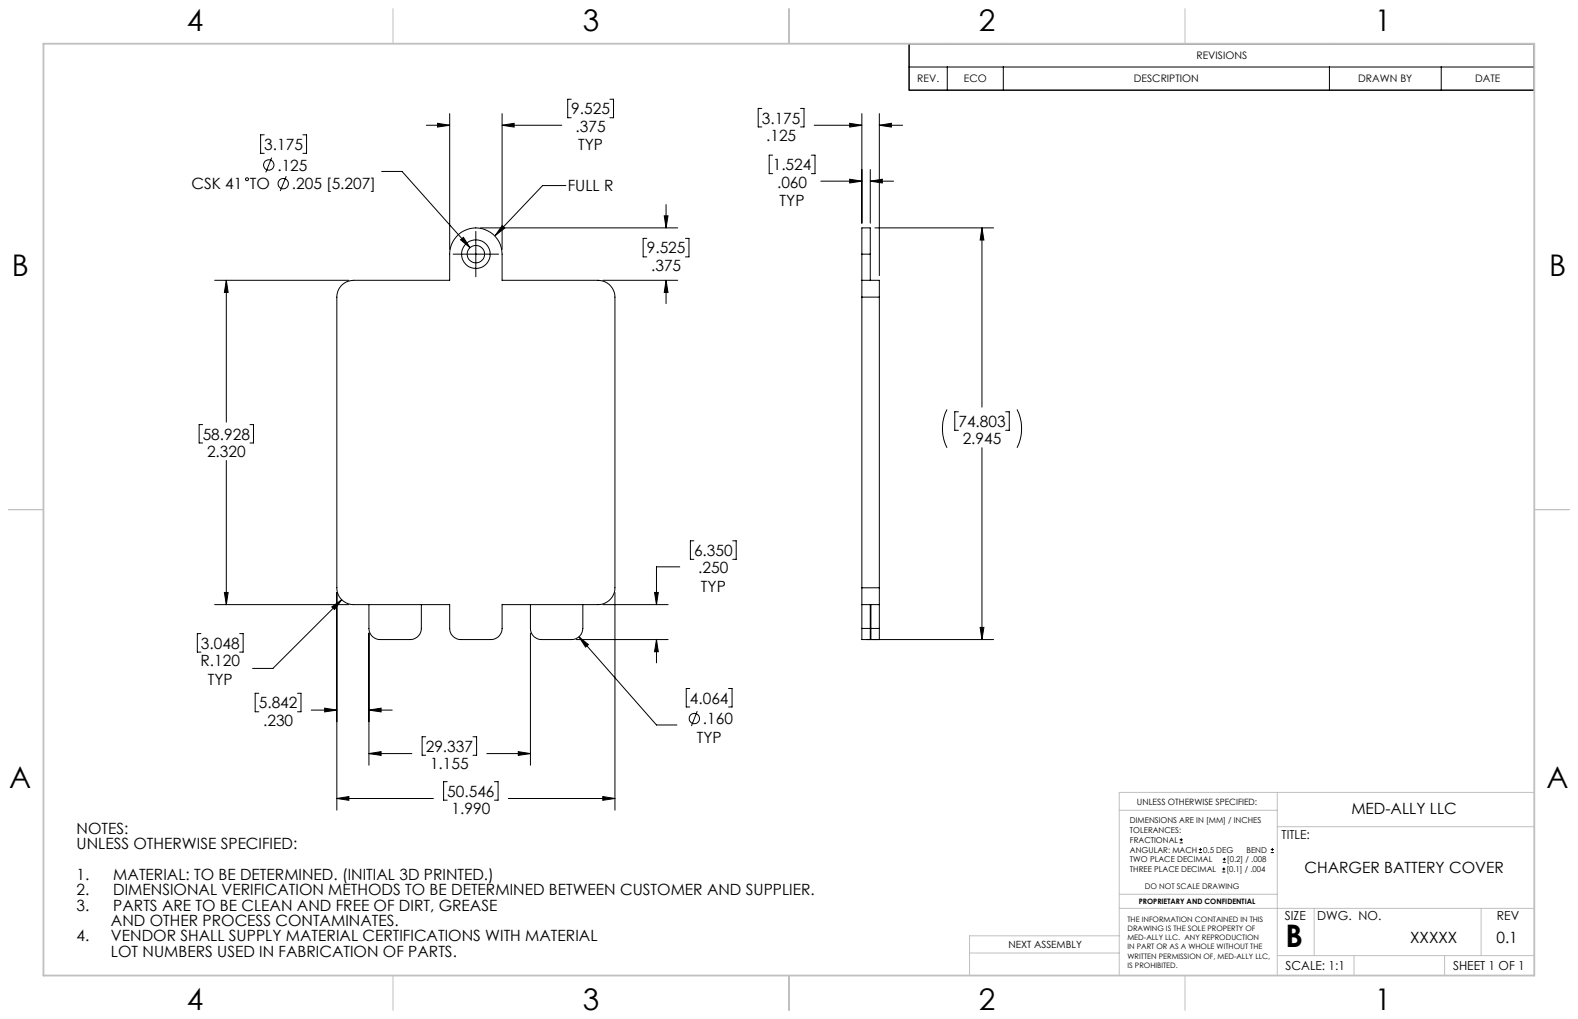
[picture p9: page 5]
CSK 41 TO .205 [5.207]; FULL R; CHARGER BATTERY COVER; DWG. NO.; REV; TWO PLACE DECIMAL

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

MED-ALLY LLC

NOTES:
1. MATERIAL: TO BE DETERMINED. (INITIAL 3D PRINTED.)
2. DIMENSIONAL VERIFICATION METHODS TO BE DETERMINED BETWEEN CUSTOMER AND SUPPLIER.
3. PARTS ARE TO BE CLEAN AND FREE OF DIRT, GREASE
AND OTHER PROCESS CONTAMINATES.
4. VENDOR SHALL SUPPLY MATERIAL CERTIFICATIONS WITH MATERIAL
LOT NUMBERS USED IN FABRICATION OF PARTS.

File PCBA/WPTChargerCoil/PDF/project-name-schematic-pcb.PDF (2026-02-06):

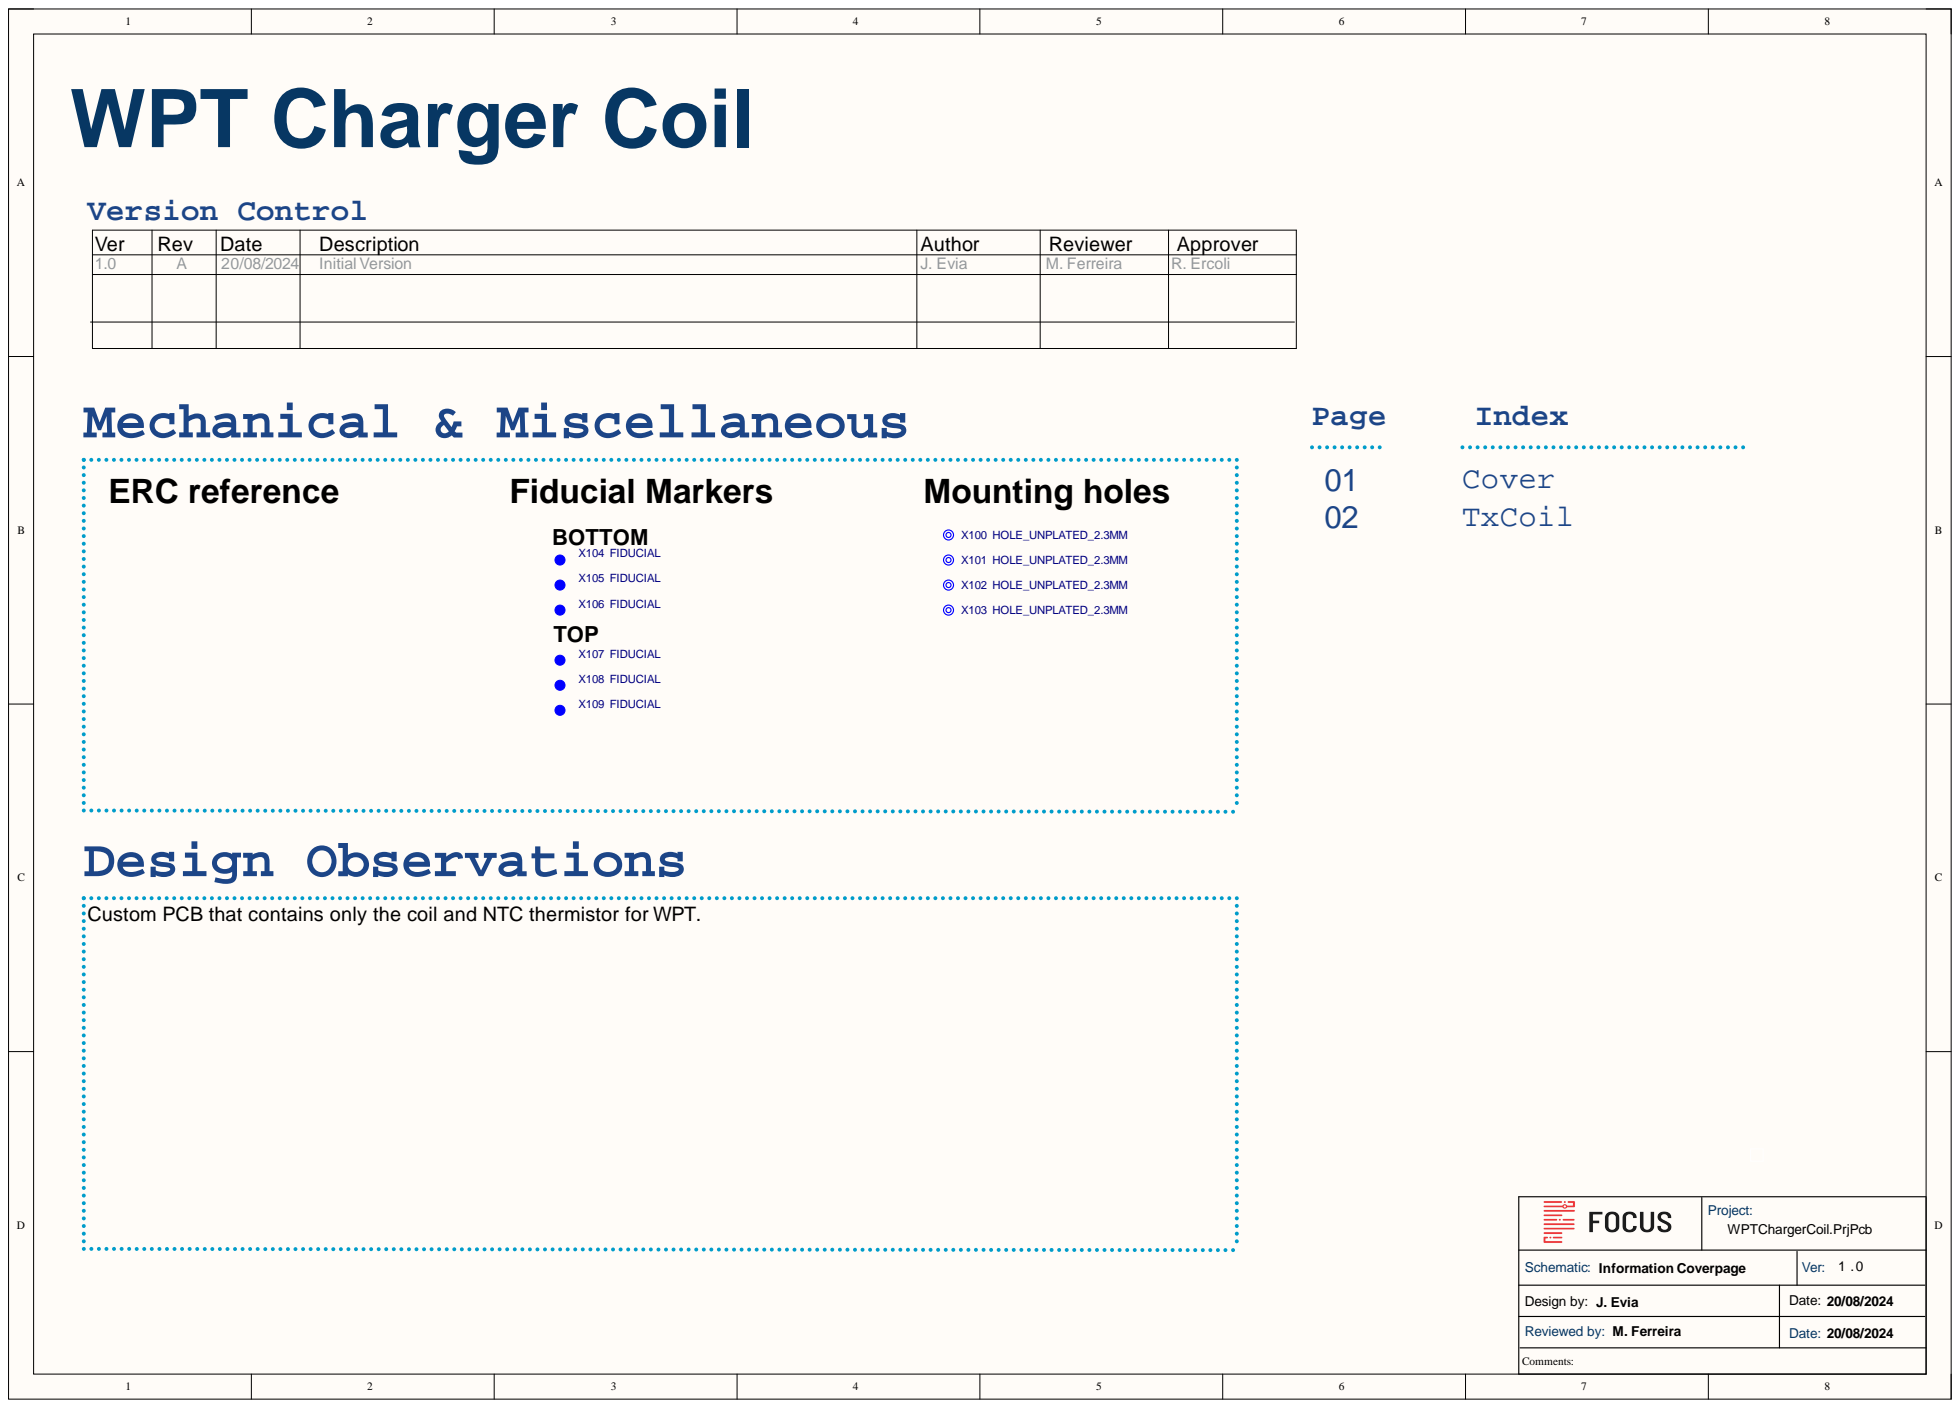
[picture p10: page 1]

Ve r | Re v | Date | De s cripti o n | Auth o r | Re viewe r | Ap pro v e r
1 . 0 | A | 2 0/0 8 /2 0 2 4 | Initial V e rsio n | J. Evia | M. Fe r r eir a | R. E rcoli

Pro j ect : WPT C h arg erC o i l .PrjPc b

Sch ema t i c : I nfo r m ati o n C o v e r p a g e | V e r : 1 . 0

D esi g n by: J . Ev i a | D a t e : 2 0/ 0 8/ 2 0 2 4

R evi e w e d by: M. F e r r e i r a | D a t e : 2 0/ 0 8/ 2 0 2 4

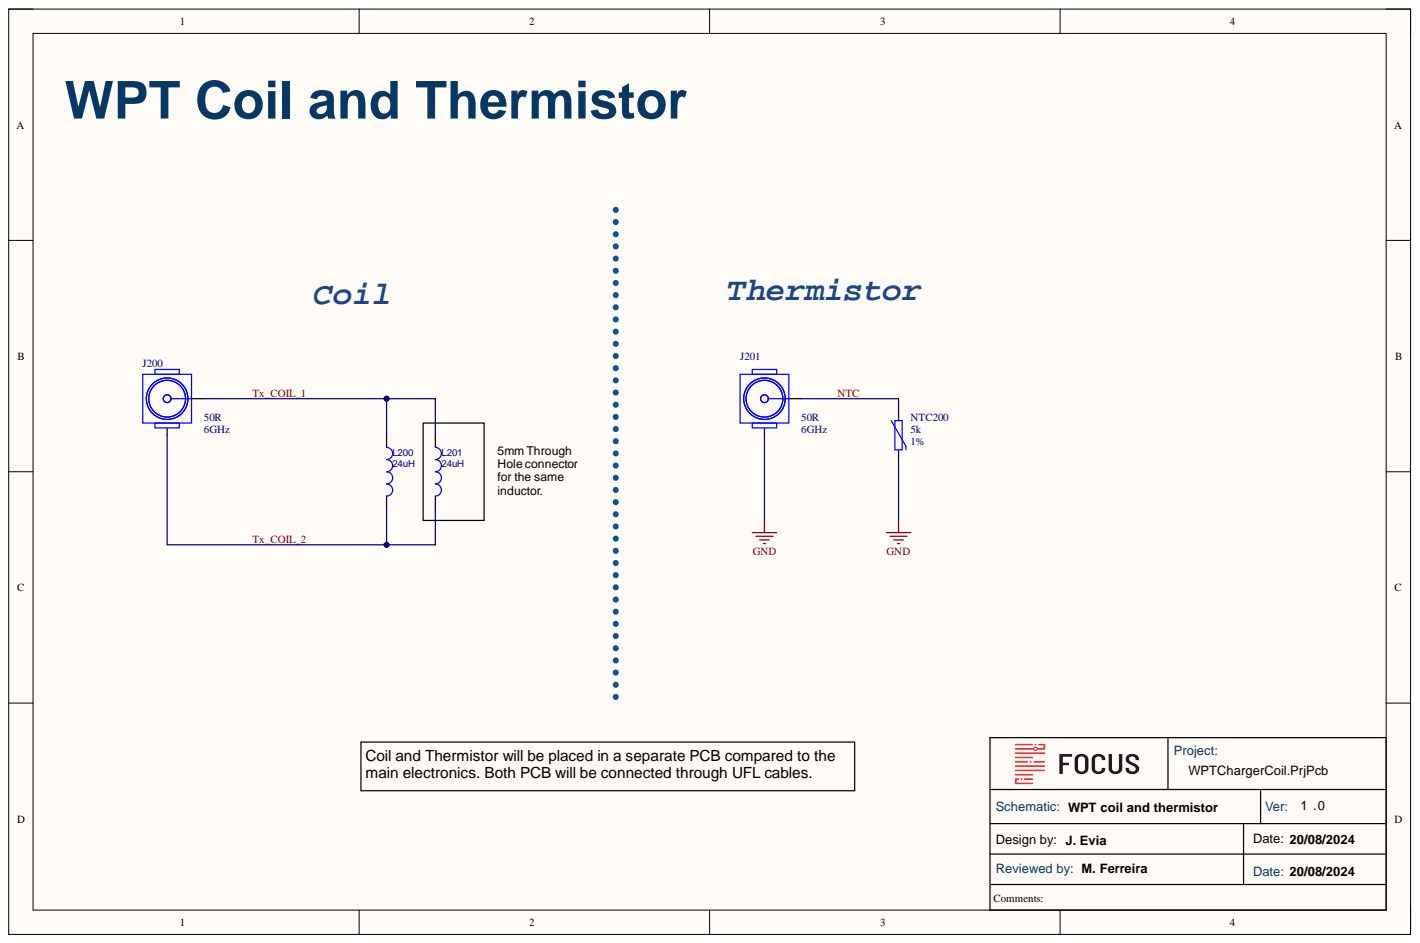
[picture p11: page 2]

WPT Coil and Thermistor

T x _COIL_ 2 | L 2 0 0 2 4 u H

P roject: WP TChargerCoil.P

Coi
l and Thermistor
main electronics. Both PCB

in a separate PCB compared

Schematic: WP T coil an d t her mist o r | Ver : 1

Design by: J. Evia M. Fer | Date: 20/08/2024

Reviewed by: reir a | 20/08/2024 Date:

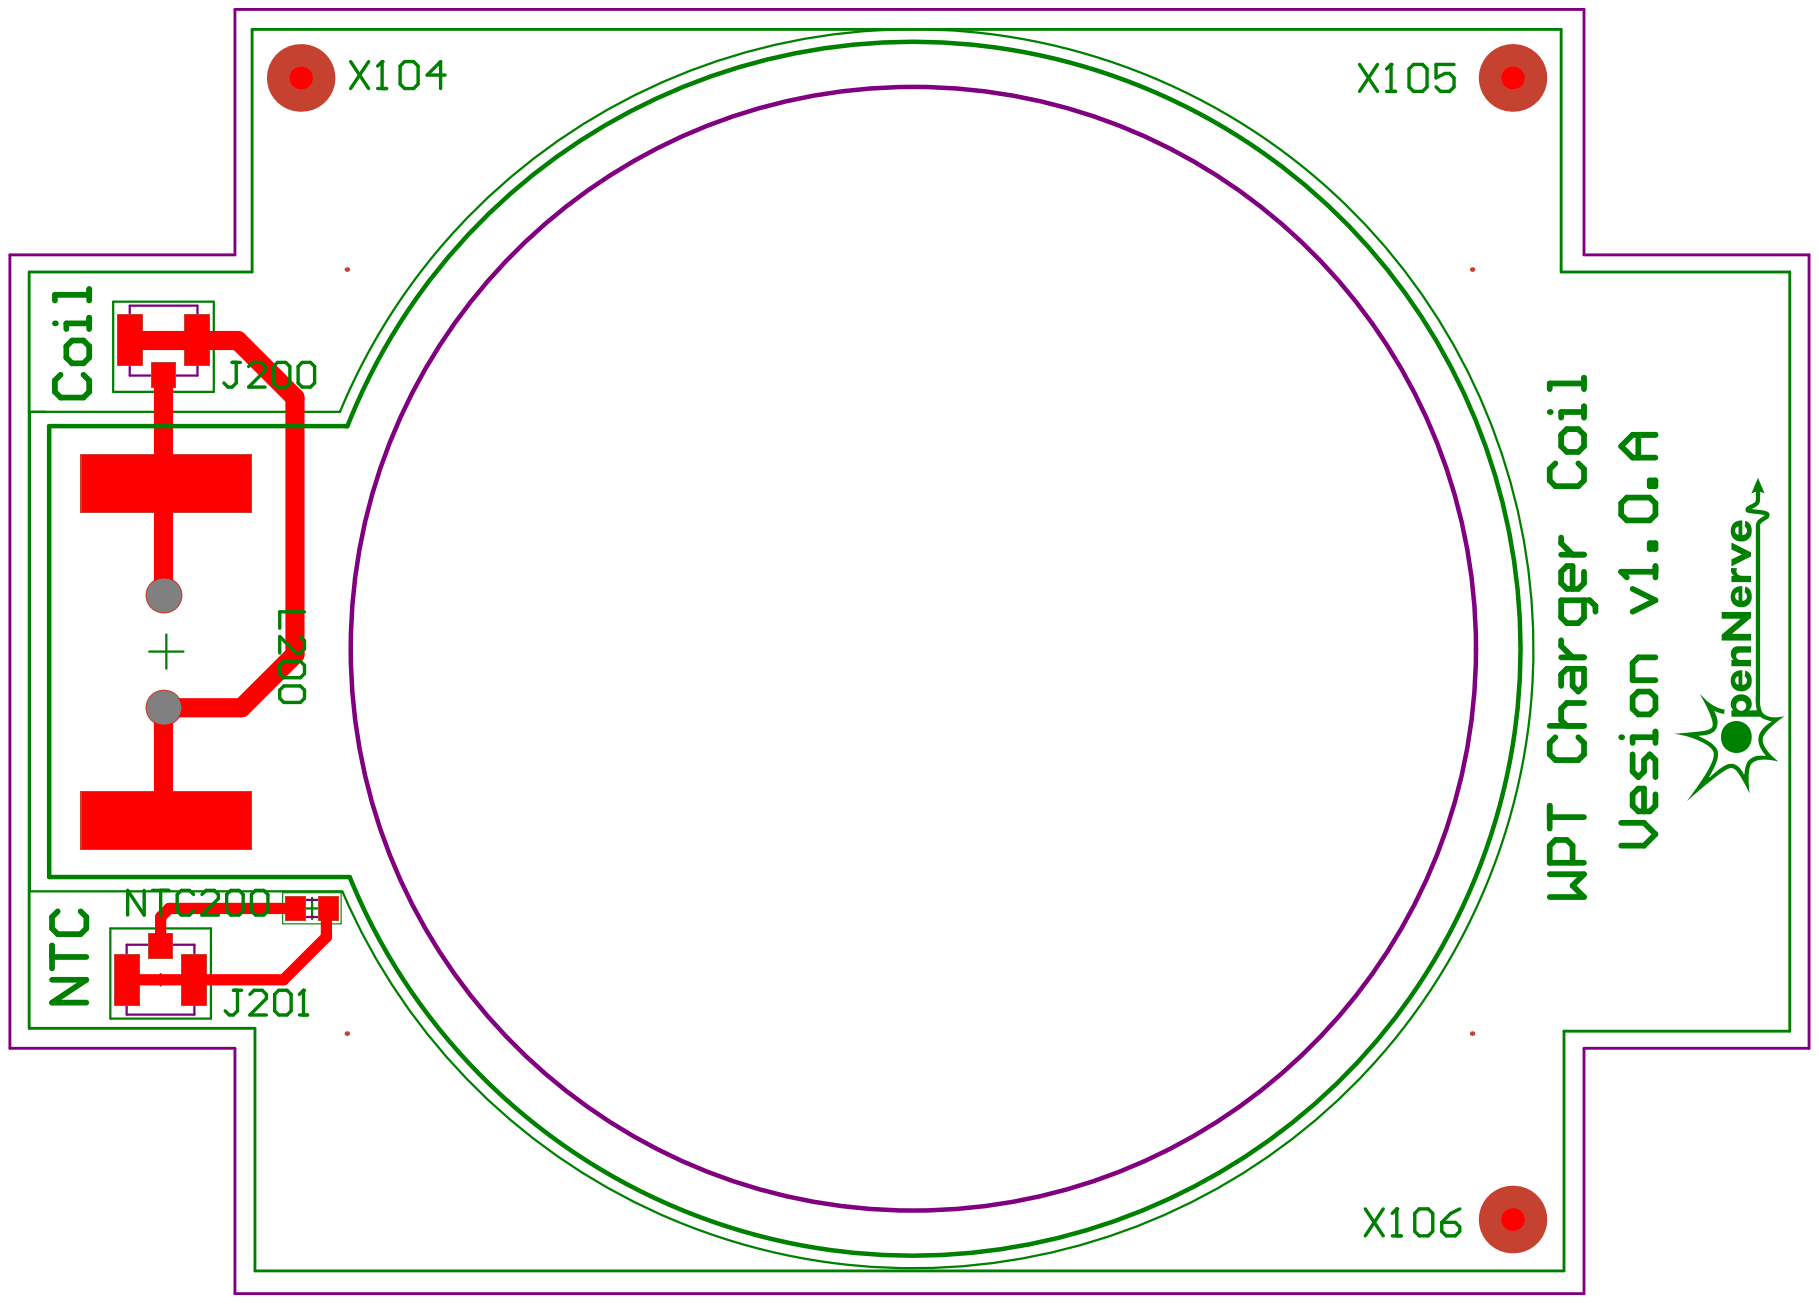
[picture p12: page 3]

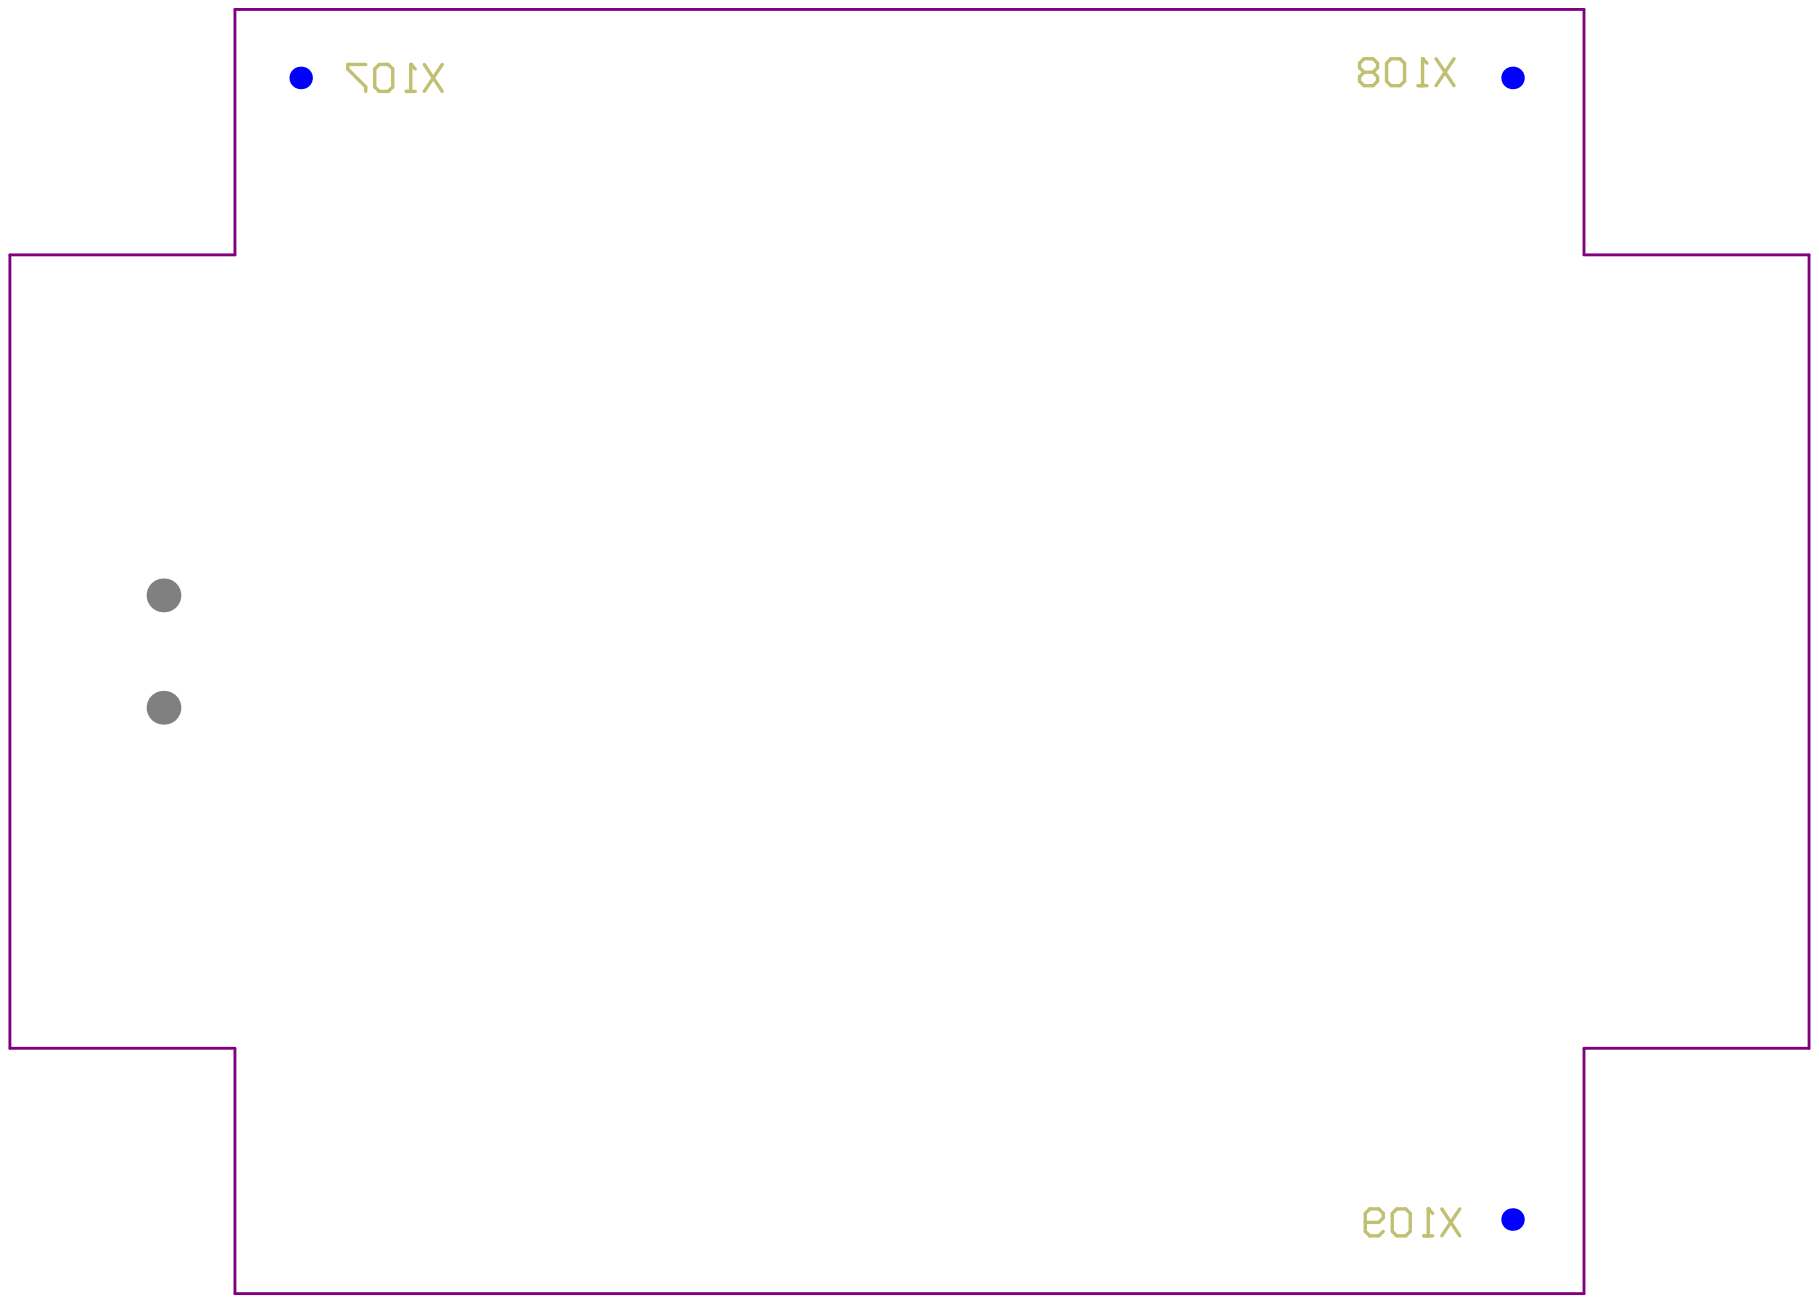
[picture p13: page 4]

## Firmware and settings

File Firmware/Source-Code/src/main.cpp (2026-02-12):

#include "../../application_layer/app_system.h"


static void disable_nfc_pins_if_needed(void)
{   
    //check if NFC pins are enabled
    if (NRF_UICR->NFCPINS == 0) {
        return; 
    }
    //enable write to NVMC
    NRF_NVMC->CONFIG = NVMC_CONFIG_WEN_Wen;
    while (NRF_NVMC->READY == NVMC_READY_READY_Busy) { }
    //disable NFC pins
    NRF_UICR->NFCPINS = 0;

    while (NRF_NVMC->READY == NVMC_READY_READY_Busy) { }
    //disable write to NVMC
    NRF_NVMC->CONFIG = NVMC_CONFIG_WEN_Ren;
    while (NRF_NVMC->READY == NVMC_READY_READY_Busy) { }

    NVIC_SystemReset();
}

int main()
{   
    disable_nfc_pins_if_needed();
    app::System &systemInstance = app::System::GetInstance();
    systemInstance.Init();
    systemInstance.Run();

    return 0;
}

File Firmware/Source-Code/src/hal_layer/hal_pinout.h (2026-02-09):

/**
 * @name Hornet / WPT Charger
 * @file hal_pinout.h
 * @brief Pinout Hardware Abstraction Layer for nrf52840
 *
 * @copyright Copyright (c) 2024
 *
 */

#ifndef HAL_PINOUT_H
#define HAL_PINOUT_H

#include "../project/config.h"

#include "nrf_gpio.h"

#if BOARD == PCBA

#define PIN_nRESET

// UART
#define PIN_UART_RX NRF_GPIO_PIN_MAP(0, 24)
#define PIN_UART_TX NRF_GPIO_PIN_MAP(0, 23)

// SPI
#define PIN_SCLK NRF_GPIO_PIN_MAP(1, 9)
#define PIN_MOSI NRF_GPIO_PIN_MAP(1, 8)
#define PIN_MISO NRF_GPIO_PIN_MAP(0, 8)
#define PIN_DAC_CS NRF_GPIO_PIN_MAP(0, 11)

// Battery
#define PIN_CHG_EN NRF_GPIO_PIN_MAP(0, 9)
#define PIN_CHG_PPR NRF_GPIO_PIN_MAP(0, 21)
#define PIN_CHG_CHG NRF_GPIO_PIN_MAP(0, 22)
#define PIN_CHG_FAST NRF_GPIO_PIN_MAP(0, 10)
#define PIN_CHG_ISET NRF_GPIO_PIN_MAP(0, 2)
#define PIN_BAT_MEAS NRF_SAADC_INPUT_AIN4

// PMC
#define PIN_PMC_VCC_EN NRF_GPIO_PIN_MAP(0, 20)

// WPT IC Signals
#define PIN_WPT_NTC NRF_SAADC_INPUT_AIN6
#define PIN_WPT_IMON NRF_SAADC_INPUT_AIN5
#define PIN_WPT_STAT NRF_GPIO_PIN_MAP(0, 7)
#define PIN_WPT_EN NRF_GPIO_PIN_MAP(1, 15)
#define PIN_WPT_CTD NRF_GPIO_PIN_MAP(0, 5)

// DAC
#define PIN_DAC_LDAC NRF_GPIO_PIN_MAP(0, 12)

// Buttons
#define PIN_BUTTON1 NRF_GPIO_PIN_MAP(0, 19)
#define PIN_BUTTON2 NRF_GPIO_PIN_MAP(0, 17)
#define PIN_BUTTON3 NRF_GPIO_PIN_MAP(0, 13)

// LED 1
#define PIN_LEDS NRF_GPIO_PIN_MAP(0, 14)

// Buzzer
#define PIN_BUZZER NRF_GPIO_PIN_MAP(0, 4)

#endif // BOARD == PCBA

#if BOARD == DEV_KIT
 
#define PIN_nRESET

// UART
#define PIN_UART_RX NRF_GPIO_PIN_MAP(0, 27)
#define PIN_UART_TX NRF_GPIO_PIN_MAP(1, 1)

// SPI
#define PIN_SCLK NRF_GPIO_PIN_MAP(1, 15)
#define PIN_MOSI NRF_GPIO_PIN_MAP(1, 13)
#define PIN_MISO NRF_GPIO_PIN_MAP(1, 14)
#define PIN_DAC_CS NRF_GPIO_PIN_MAP(1, 12)

// Battery
#define PIN_CHG_EN NRF_GPIO_PIN_MAP(0, 23)
#define PIN_CHG_PPR NRF_GPIO_PIN_MAP(0, 24)
#define PIN_CHG_CHG NRF_GPIO_PIN_MAP(0, 25)
#define PIN_CHG_FAST NRF_GPIO_PIN_MAP(0, 26)
#define PIN_CHG_ISET NRF_GPIO_PIN_MAP(0, 06)
#define PIN_BAT_MEAS NRF_SAADC_INPUT_AIN4

// PMC
#define PIN_PMC_VCC_EN NRF_GPIO_PIN_MAP(0, 19)

// WPT IC Signals
#define PIN_WPT_NTC NRF_GPIO_PIN_MAP(0, 29)
#define PIN_WPT_IMON NRF_GPIO_PIN_MAP(0, 31)
#define PIN_WPT_STAT NRF_GPIO_PIN_MAP(0, 20)
#define PIN_WPT_EN NRF_GPIO_PIN_MAP(0, 28)

// DAC
#define PIN_DAC_LDAC NRF_GPIO_PIN_MAP(0, 17)
#define PIN_DAC_REF NRF_GPIO_PIN_MAP(0, 30)

// Buttons
#define PIN_BUTTON1 NRF_GPIO_PIN_MAP(0, 11)
#define PIN_BUTTON2 NRF_GPIO_PIN_MAP(1, 12)
#define PIN_BUTTON3 NRF_GPIO_PIN_MAP(1, 24)

// LED 1
#define PIN_LEDS NRF_GPIO_PIN_MAP(0, 4) //Works on devkit

// Buzzer
#define PIN_BUZZER NRF_GPIO_PIN_MAP(0, 14)

#endif // BOARD == DEV_KIT

#endif // PINOUT_H

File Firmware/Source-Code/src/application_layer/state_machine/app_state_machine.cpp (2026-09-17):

/**
 * @name Hornet / WPT Charger
 * @file app_state_machine.cpp
 * @brief Implementation file for the application state machine
 *
 * @copyright Copyright (c) 2024
 *
 */

#include "app_state_machine.h"

#include "app_system.h"
#include "hal_button.h"
#include "hal_gpio.h"
#include "hal_pinout.h"
#include "hal_led.h"
#include "svc_ble_subsystem.h"
#include "svc_wpt_subsystem.h"
#include "svc_ble_port.h"
#include "svc_wpt_port.h"

#include <cstdint>

namespace app
{
    SystemStateMachine::SystemStateMachine() : StateMachine("App", &mInitialState), mInitialState(this), mStateCharge(this), mStateScan(this), mStateWait(this), mStateSlowChargeAndScan(this)
#if WPT_MANUAL_DEBUG_MODE
        , mStateManual(this)
#endif
    {
    }

    void SystemStateMachine::InitAction()
    {
        SetBleServiceCallbacks();
        SetWptServiceCallbacks();
        hal::Button::Init();
        static hal::Button onOffButton(PIN_BUTTON1, &OnOffButtonCallback, nullptr);
        static hal::Button DfuButton(PIN_BUTTON3, &DfuButtonCallback, nullptr);
        static hal::Button resetButton(PIN_BUTTON2, &ResetButtonCallback, nullptr);

        hal::Leds::Initialize();
        hal::Leds& leds = hal::Leds::GetInstance();
        leds.TurnLedOff(&leds.rgb_led);
   }

    StatePointers *SystemStateMachine::GetStates()
    {
        static StatePointers states;
        states.pInitialState = &mInitialState;
        states.pStateCharge = &mStateCharge;
        states.pStateScan = &mStateScan;
        states.pStateWait = &mStateWait;
        states.pStateSlowChargeAndScan = &mStateSlowChargeAndScan;
#if WPT_MANUAL_DEBUG_MODE
        states.pStateManual = &mStateManual;
#endif
        return &states;
    }

    void SystemStateMachine::ProcessNewBleData(uint32_t optDataAddress)
    {
        System *pSystem = &System::GetInstance();

        // Use the getter to get new data
        const svc::AdvertisementData_t &advData = svc::BleManager::GetAdvertisementData();
        svc::ChargingStatusParameters_t ChargingStatusParameters = advData.chargingStatusParameters;

        LOG_INFO("StateMachine: New IPG data received");

        LOG_INFO("Charging Parameters:");
        // Raw pin levels as the IPG sent them. Every name ending in "n" is
        // active-low: 1 = OK/absent, 0 = asserted.
        LOG_INFO("  VRECT_DETn: %d (0 = coil present)", ChargingStatusParameters.GET_VRECT_DET);
        LOG_INFO("  VRECT_OVPn: %d (1 = OK, 0 = OVP)", ChargingStatusParameters.GET_VRECT_OVP);
        LOG_INFO("  Vchg rail supply circuit power good: %d",
                 ChargingStatusParameters.GET_VCHG_RAIL_SUPPLY_CIRCUIT_POWER_GOOD);
        LOG_INFO("  CHG1 status: %d, CHG1_OVP_ERRn: %d (1 = OK, 0 = OVP)",
                 ChargingStatusParameters.GET_CHG1_STATUS, ChargingStatusParameters.GET_CHG1_OVP_ERR);
        LOG_INFO("  CHG2 status: %d, CHG2_OVP_ERRn: %d (1 = OK, 0 = OVP)",
                 ChargingStatusParameters.GET_CHG2_STATUS, ChargingStatusParameters.GET_CHG2_OVP_ERR);

        LOG_INFO("Thermal Parameters:");
        LOG_INFO("  Therm reference: %d", ChargingStatusParameters.GET_THERM_REF);
        LOG_INFO("  Therm ouput: %d", ChargingStatusParameters.GET_THERM_OUT);
        LOG_INFO("  Therm offset: %d", ChargingStatusParameters.GET_THERM_OFST);

        // BattA in the lower 16 bits, BattB in the upper 16 bits (see ParseManufacturerSpecificData).
        const uint16_t battA_mV = static_cast<uint16_t>(ChargingStatusParameters.BATTERY_VOLTAGE_MEASURED & 0xFFFF);
        const uint16_t battB_mV = static_cast<uint16_t>(ChargingStatusParameters.BATTERY_VOLTAGE_MEASURED >> 16);
        LOG_INFO("Battery voltage measured: BattA=%u mV BattB=%u mV", battA_mV, battB_mV);

        LOG_INFO("Test Information:");
        LOG_INFO("  HV Supply Enable: %d", ChargingStatusParameters.GET_TEST_INFO & 0xFF);
        LOG_INFO("  VDDS Supply Enable: %d", (ChargingStatusParameters.GET_TEST_INFO & 0xFF00) >> 8);
        LOG_INFO("  VDDA Supply Enable: %d", (ChargingStatusParameters.GET_TEST_INFO & 0xFF0000) >> 16);

        // Determine charging completion robustly across one or two batteries.
        //
        // CHG1_STATUS and CHG2_STATUS each report 0=actively charging, 1=idle/full.
        // The idle/full value (1) is not proof of a full battery: it also appears when
        // the charger IC has no input power yet, and with a deeply discharged battery
        // (seen at BattB = 2.5 V with PGOOD = 1). CHG1 reads 1 in every state seen on
        // this hardware.
        //
        // So a battery is only "done" when its measured voltage agrees. A channel reading
        // below BATTERY_PRESENT_MV is absent or not yet measured and is left out (an
        // unpopulated BattA reads 0-200 mV); if no channel has a reading at all, nothing can be concluded and charging continues (the LTC4065
        // terminates on its own and the IPG has its own thermal protection).
        //
        // Rules:
        //   - PGOOD = 0                        → charger ICs not powered; keep charging.
        //   - Any measured channel with CHG = 0
        //     or mV < BATTERY_FULL_MV          → still charging.
        //   - No measured channel              → unknown; keep charging.
        //   - Otherwise                        → all charging is complete.
        //
        // BATTERY_CHARGED is only acted on in StateCharge, whose Exit() stops scanning.
        // Scanning must not be stopped from here: in StateSlowChargeAndScan / StateScan
        // the event is ignored, and a stopped scan would leave WPT running with no
        // telemetry and no scan timeout to restart it.

        static constexpr uint16_t BATTERY_FULL_MV    = 4100; // LTC4065 float is 4.2 V; ad resolution 100 mV
        static constexpr uint16_t BATTERY_PRESENT_MV = 1000; // Below this the channel has no battery

        const bool pgood = (ChargingStatusParameters.GET_VCHG_RAIL_SUPPLY_CIRCUIT_POWER_GOOD == 1);

        const bool battA_measured = (battA_mV >= BATTERY_PRESENT_MV);
        const bool battB_measured = (battB_mV >= BATTERY_PRESENT_MV);
        const bool battA_done = (ChargingStatusParameters.GET_CHG1_STATUS == 1) && (battA_mV >= BATTERY_FULL_MV);
        const bool battB_done = (ChargingStatusParameters.GET_CHG2_STATUS == 1) && (battB_mV >= BATTERY_FULL_MV);

        const bool all_done = pgood
                              && (battA_measured || battB_measured)
                              && (!battA_measured || battA_done)
                              && (!battB_measured || battB_done);
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

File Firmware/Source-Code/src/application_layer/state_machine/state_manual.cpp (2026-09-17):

/**
 * @name Hornet / WPT Charger
 * @file state_manual.cpp
 * @brief Implementation file for the manual (bench debug) state
 *
 * @copyright Copyright (c) 2024
 *
 */

#include "state_manual.h"

#if WPT_MANUAL_DEBUG_MODE

#include "app_port.h"
#include "app_state_machine.h"
#include "eda_manager_log_config.h"
#include "hal_dfu.h"
#include "hal_led.h"
#include "svc_ble_port.h"
#include "svc_debug_console.h"
#include "svc_ble_subsystem.h"
#include "svc_pmc_port.h"
#include "svc_pmc_subsystem.h"
#include "svc_wpt_port.h"
#include "svc_wpt_subsystem.h"

namespace app
{
    struct StatePointers;

    void StateManual::Entry()
    {
        // The state owns the console's manual flag, so the two can never disagree.
        svc::DebugConsole::OnManualEntered();

        // VCC_EN. The LTC4125's 5 V supply is owned entirely by the PMC state
        // machine and is low at boot, so without this the console can drive
        // PIN_WPT_EN all it likes into an unpowered transmitter.
        svc::PmcSubSystem &mPmcSubSystem = svc::PmcSubSystem::Instance();
        mPmcSubSystem.mPmcPort.SendEvent(svc::PmcPort::Event_e::PMC_POWER_ON, NULL);

        // StateCharge::Entry() deliberately does not start scanning - it assumes a
        // predecessor state did. Manual mode can be entered straight from
        // StateWait, so it has to start its own, or there is no IPG telemetry and
        // the thermal/OVP warnings have nothing to report.
        svc::BleSubsystem &mBleSubsystem = svc::BleSubsystem::Instance();
        mBleSubsystem.mBlePort.SendEvent(svc::BlePort::Event_e::START_SCANNING, NULL);

        // Stop whatever the previous state left running and settle the WPT side in
        // StateIdle with fault monitoring only. This has to be an event rather than
        // a direct call: the previous state's Exit() may have queued WPT_POWER_ON
        // (StateScan) or WPT_POWER_OFF (StateCharge) that the WPT task, running at
        // lower priority, has not processed yet. Queued behind them, this runs last.
        svc::WptSubsystem &mWptSubsystem = svc::WptSubsystem::Instance();
        mWptSubsystem.mWptPort.SendEvent(svc::WptPort::Event_e::WPT_MANUAL_IDLE, NULL);

        hal::Leds &leds = hal::Leds::GetInstance();
        leds.SetLedColor(&leds.rgb_led, hal::LedPosition_e::LED1, hal::LedColor_e::MAGENTA);
        leds.TurnLedOn(&leds.rgb_led);

        // The coil stays off until the operator presses 's'.
        LOG_WARNING("Manual State: VCC rail ON, WPT idle, coil HELD OFF - press 's' to transmit\n");
    }

    void StateManual::DispatchEvent(uint32_t eventId, uint32_t optDataAddress)
    {
        SystemStateMachine *stateMachine = reinterpret_cast<SystemStateMachine *>(mStateMachine);

        StatePointers *states = stateMachine->GetStates();

        switch (static_cast<SystemPort::Event_e>(eventId))
        {
        case SystemPort::Event_e::TURN_OFF:
            // The console's 'n' command.
            LOG_WARNING("Manual State: manual mode ended, shutting down\n");
            stateMachine->ChangeState(states->pStateWait);
            break;

        case SystemPort::Event_e::BUTTON_PRESSED:
            // Button 1 is disabled in manual mode. The only ways out are the
            // console's 'n' and Button 2, which resets the MCU from its ISR.
            LOG_WARNING("Manual State: Button 1 ignored in manual mode - use 'n', or Button 2 to reset\n");
            break;

        case SystemPort::Event_e::BLE_SCAN_TIMEOUT:
            // Re-arm rather than leave the state. This is the same trick
            // StateCharge uses, and it is what keeps a manual session alive
            // indefinitely with no IPG present.
            {
                svc::BleSubsystem &mBleSubsystem = svc::BleSubsystem::Instance();
                mBleSubsystem.mBlePort.SendEvent(svc::BlePort::Event_e::START_SCANNING, NULL);
            }
            break;

        case SystemPort::Event_e::BATTERY_CHARGED:
            // ProcessNewBleData() has already sent STOP_SCANNING straight to the BLE
            // port, which also stops the scan watchdog - so no BLE_SCAN_TIMEOUT
            // would follow to re-arm it, and IPG telemetry would freeze for the rest
            // of the session. Low-PTH bench runs produce this reading routinely.
            {
                svc::BleSubsystem &mBleSubsystem = svc::BleSubsystem::Instance();
                mBleSubsystem.mBlePort.SendEvent(svc::BlePort::Event_e::START_SCANNING, NULL);
            }
            break;

        case SystemPort::Event_e::BUTTON_DFU_PRESSED:
            if (!hal::Dfu::Instance().is_dfu_active())
            {
                hal::Dfu::Instance().start_dfu_mode();
            }
            break;

            // WPT_SCAN_TIMEOUT and BLE_DEVICE_FOUND are absent on purpose: in manual
            // mode the operator decides when power starts and stops.
        }
    }

    void StateManual::Exit()
    {
        svc::DebugConsole::OnManualExited();

        // Stop the fault timer explicitly. WPT_POWER_OFF below only reaches
        // DisableWpt() when the WPT state machine is in a charging state; if the
        // operator never pressed 's' it is still in StateIdle and the event is
        // dropped, which would leave the timer running after the state is gone.
        mWptManager.StopIpgTemperaturePgoodMonitoringTimer();

        svc::WptSubsystem &mWptSubsystem = svc::WptSubsystem::Instance();
        mWptSubsystem.mWptPort.SendEvent(svc::WptPort::Event_e::WPT_POWER_OFF, NULL);

        svc::BleSubsystem &mBleSubsystem = svc::BleSubsystem::Instance();
        mBleSubsystem.mBlePort.SendEvent(svc::BlePort::Event_e::STOP_SCANNING, NULL);

        // Required. StateCharge::Exit() does not drop the rail, which is why
        // leaving that state the normal way parks VCC_EN high.
        svc::PmcSubSystem &mPmcSubSystem = svc::PmcSubSystem::Instance();
        mPmcSubSystem.mPmcPort.SendEvent(svc::PmcPort::Event_e::PMC_POWER_OFF, NULL);

        hal::Leds &leds = hal::Leds::GetInstance();
        leds.TurnLedOff(&leds.rgb_led);
    }
} // namespace app

#endif // WPT_MANUAL_DEBUG_MODE

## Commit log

2026-02-06 Added firmware .hex files and PCBA Altium files
    [01-Cover.SchDoc, 02-BlockDiagram.SchDoc, 02-TxCoil.SchDoc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]
2026-02-07 Fixed LED bug
2026-02-10 Changed BLE scan from 2s to 10s and changed CARSS ID to match production boards, both in scv_ble_manager.h
2026-02-12 Fixed bug in battery charging GPIO pin
    [main.cpp]
2026-03-16 Added PGOOD-based control system for modulating charge voltage to IPG
2026-03-16 Increased slow charge state to 30s, confirmed that this is long enough for slow charging to wake IPG up from magnet off mode
2026-03-16 Added summary of charger firmware
2026-03-25 Fixed bug where VDD (+5V) did not turn on during slow charge and scan
2026-04-11 Modified middle button to be emergency reset
    [app_state_machine.cpp]
2026-05-15 Updated charger firmware report
2026-09-03 New charging titration and temperature regulation algorithm
2026-09-10 Fixed issue with battery IC error being mistaken for overpotential on coil
    [app_state_machine.cpp]
2026-09-10 Fix for temperature wraparound issue - not yet tested
2026-09-11 Added flag to disable max power during cold start, increased cold start time at level 7 to 30s
2026-09-17 Fixes for charging bugs with low batteries
    [app_state_machine.cpp]
2026-09-17 Updated charging report
2026-09-17 Changed cold start powering so it starts at level 1 (lowest level) and steps up every 30s
2026-09-18 Adjusted lock on reset settings in debug mode so that power cycling and then re-connecting RTT doesn't erase the chip
    [main.cpp]
2026-09-18 Added logic to fix a bug where if BLE ad dissapears during charging, device will stay charging at a lower level indefinitely
2026-09-24 Added stl files for 3D printing enclosure
